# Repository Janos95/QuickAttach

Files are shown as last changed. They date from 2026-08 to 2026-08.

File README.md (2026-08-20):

# SO-101 powered magnetic quick changer v0.2

This is a retrofit, passively docked quick changer for an existing SO-101. Two
permanent magnets perform forgiving capture and face preload; they are **not**
the safety lock. A spring-return stainless keyhole slider positively captures
two metal pull studs. The passive rack cams that slider open, so the robot only
needs straight approach/withdrawal and one rack-exit translation—no wrist
twist, release servo, solenoid, or electromagnet.

The same interface carries power and the existing half-duplex TTL bus. The
first tool can therefore be the standard SO-101 gripper on a detachable adapter
plate while its STS3215 remains motor ID 6.

The calibrated arm model, mesh assets, and stock-gripper STEP used here are
derived from TheRobotStudio/SO-ARM100. Exact source revision and license details
are recorded in the repository-root `THIRD_PARTY_NOTICES.md`.

## What is where

- **Robot side:** 48 x 48 x 9.5 mm main plate, plus a left electrical wing;
  overall envelope 60 x 48 mm. It replaces the gripper at the four existing
  holes on the measured 9.9 mm-square wrist-horn pattern.
- **Magnets:** two purple 12 x 12 x 4 mm blocks, flush in the robot plate at
  `(x, y) = (0, -16)` and `(0, +16)` mm. Each is mechanically fastened, not
  glued.
- **Tool side:** 56 x 50 x 9.5 mm main plate, overall envelope 64 x 50 mm. It
  carries two matching 12 x 12 x 3 mm Q235 steel targets, not more magnets, so
  tool polarity is irrelevant.
- **Location:** two 3.5 mm tapered pins; the second socket is tangentially
  relieved to avoid an over-constrained fit.
- **Positive lock:** two 4 mm pull-stud shoulders enter 6.5 mm keyholes. On
  leaving the rack, the E-GUL4-10 return spring shifts a 1.6 mm stainless slider
  by 3 mm so 4.25 mm necks sit under the 6 mm stud heads. The printed roof, not
  the M2 guide screw, reacts separation load. Loss of power leaves it locked.
- **Electrical interface:** four Mill-Max pins on 5 mm pitch: GND, +12 V,
  TTL_DATA, and a spare TOOL_ID line. GND protrudes 0.2 mm farther so it mates
  first and breaks last.

In the CAD and MuJoCo model, purple identifies the two magnets, silver their
targets and pull studs, green the positive-lock slider, and gold the four
contacts. Use the full-arm MuJoCo example below as the executable acceptance
check.

## Attach and detach sequence

1. Approach the docked tool axially. Tapered locators enter first; magnets then
   close the final gap and compress the contacts.
2. Verify contact—for the first gripper, read servo ID 6 with torque still off.
3. Translate out of the rack. The rack releases the slider tab and the spring
   closes the positive lock.
4. Enable the tool and work normally.
5. To detach, command gripper torque off and stop bus packets, then return the
   still-locked assembly to the rack.
6. During the final rack travel, the fixed wedge pushes the exposed tab 3 mm,
   aligning both large keyholes with the stud heads.
7. The rack retains the tool plate while the arm withdraws axially. Contacts and
   magnets separate; no powered release actuator is involved.

The MuJoCo model uses conditional welds for capture and lock state. It validates
this state sequence and geometry; it does not predict magnetic fields, contact
arcing, printed-part strength, fatigue, or wear.

## Full SO-101 detachable-gripper MuJoCo example

`sim/so101_gripper_change_demo.py` builds on the calibrated upstream
`Simulation/SO101/so101_new_calib.xml` rather than a simplified arm. At load
time it makes one deliberate topology change:

- motor 5's `wrist_roll` joint stays on the robot and receives the v0.2 robot
  plate;
- the exact stock fixed-gripper and moving-jaw mesh subtree, including the
  original `gripper` joint and actuator, moves onto
  `so101_stock_gripper_tool_plate.stl` as a free docked tool;
- that existing gripper actuator represents the normal Feetech ID-6 control
  path after the pogo-pin bus is connected.

The deterministic sequence begins with a 55 mm gap, approaches the dock with
constant coupling orientation, changes from a rack weld to magnetic capture,
changes to the fail-locked positive-lock constraint as the arm withdraws, then
opens and closes the stock jaw through the unchanged gripper actuator. It then
returns the still-locked tool to the rack, switches off the simulated bus,
opens the rack-actuated lock, and withdraws the bare wrist. It exits nonzero
unless the complete attach/lock/use/return/release cycle, 45+ mm withdrawal in
both directions, coupling retention, and at least 0.8 rad of ID-6 jaw travel
are all observed.

From the repository root:

```bash
.venv/bin/pip install -r Simulation/SO101/requirements.txt
.venv/bin/python QuickChange/SO101_Magnetic/sim/so101_gripper_change_demo.py
```

For CI or a machine without a display:

```bash
.venv/bin/python QuickChange/SO101_Magnetic/sim/so101_gripper_change_demo.py --headless
```

The canonical presentation is the interactive Three.js app in
[`web/quickattach-control`](web/quickattach-control). It starts with a bare
wrist and all three tools in the printable fixture, supports orbit/top camera
control, joint controls, and a flange gizmo for moving, attaching, detaching,
and returning tools. Its CAD tab compares each source STL with the emitted
collision geometry.

The same browser scene is also the only video renderer. Run the page locally,
then use `web/quickattach-control/scripts/render-threejs-video.py` to drive it
through Playwright and encode an MP4 with FFmpeg. See the web app README for
exact commands. MuJoCo/Python remain the numerical validation authority; the
page and video are presentation views, not physical-release evidence.

The XML file beside the controller is a scene overlay. The controller merges it
with the upstream robot in memory so there is no duplicated SO-101 description
to fall out of sync. `--save-preview PATH.png` is optional and requires a
working OpenGL/EGL/OSMesa backend.

This simulation intentionally treats magnetic seating and the positive lock as
switched weld constraints. It checks kinematics, model topology, sequencing,
retention, and continued jaw control. It does **not** simulate field strength,
rack-cam contact, slider motion, electrical hot-plug behavior, compliance,
strength, fatigue, or wear. The ID-6 handshake is a state-machine gate rather
than a serial-protocol emulation, and quick-changer/gripper collision geometry
is disabled, so this demo does not prove physical clearance. The physical
validation plan below still applies.

## Retrofitting the standard gripper

The official assembly guide attaches the gripper to motor 5's wrist horn with
four M3x6 screws. This adapter uses that same interface and does not require
drilling or cutting the arm.

1. Power the arm down and remove the four M3x6 gripper-to-horn screws.
2. Fit the robot plate to the existing horn with four M3x10 socket-head screws.
   Confirm at least 3 mm thread engagement and no bottoming on the actual horn
   before tightening; shorten only if the particular horn requires it.
3. Install four Ruthex RX-M3x5.7 inserts in the rear of
   `so101_stock_gripper_tool_plate`.
4. Drop the two DIN 934 M3 pull-stud nuts into their rear hex pockets and fit
   the two shoulder screws from the coupling side. The gripper body captures
   the nuts when installed.
5. Attach the original printed gripper body to the tool plate with its original
   four M3x6 screws.
6. Terminate the gripper motor's three conductors on P1-P3 of the tool PCB:
   GND, +12 V, TTL_DATA. Use the four plated wire holes accessible from the rear.
7. Add a short, reversible adapter harness from the wrist-roll motor's outgoing
   gripper connector to the four robot-side pogo pins. Avoid cutting the stock
   cable; use mating 3-pin housings or a small inline adapter.

The stock gripper keeps ID 6 and is still controlled through the normal LeRobot
Feetech bus. P4 is unused for this first tool. A later controller can read P4
with a pull-up and a tool-specific resistor to ground for passive tool ID.

### Electrical mating caveat

The cited Feetech material specifies 12 V operation and half-duplex serial
control, but does not qualify the servo connector for live hot-plugging. For
the minimum retrofit, command ID 6 torque off, stop bus traffic, mate or unmate,
then verify communication before re-enabling torque. For unattended repeated
tool changing, add a robot-side switched/e-fused +12 V tool branch and enable it
only after mechanical attachment; this is an electrical reliability upgrade,
not an electromagnet.

The supplied target PCB is functional rather than just a drawing: each 4 mm
ENIG target is routed to a rear-accessible plated hole. Fabricate it as 1.0 mm
FR-4, 2 oz copper, ENIG. `electrical_pinout.csv`, the KiCad source, and an SVG
fab drawing are included. Retain the PCB by bonding only its perimeter into the
recess with an electronics-compatible epoxy; keep the ENIG targets free of
adhesive and verify that the board remains flush.

## Purchasable hardware

| Qty | Side | Part | Geometry / purpose |
|---:|---|---|---|
| 2 | robot | [Supermagnete CS-Q-12-12-04-N](https://www.supermagnete.de/eng/screw-on-neodymium-magnets/screw-on-block-magnet-12-x-12-x-4mm_CS-Q-12-12-04-N), EAN 7640172691830 | N35 NdFeB, 12 x 12 x 4 mm, M3 countersunk hole, 29.4 N nominal axial force each |
| 2/tool | tool | [Supermagnete MC-12-12-03](https://www.supermagnete.de/eng/magnet-counterparts-to-screw-on/metal-plates-with-countersunk-hole-12-x-12-x-3mm_MC-12-12-03), EAN 7640172691892 | Q235 target, 12 x 12 x 3 mm, M5 countersunk hole |
| 2/tool | tool | [McMaster 90318A720](https://www.mcmaster.com/90318A720/) | 316 SS ultra-low-profile shoulder screw; M3 thread, 4 mm shoulder diameter, 5 mm shoulder length, 6 x 1.3 mm head, 4 mm thread length |
| 2/tool | tool | [DIN 934 M3 nut](https://accu-components.com/us/hexagon-nuts/7888-HPN-M3-A2) | 5.5 mm across flats x 2.4 mm; captive pull-stud retention |
| 1 | robot | [MISUMI E-GUL4-10](https://us.misumi-ec.com/vona2/detail/110310903689/?HissuCode=E-GUL4-10) | 304 SS compression spring, OD 4 x 10 mm free, 0.98 N/mm, 4 mm permitted deflection |
| 4 | robot | [Mill-Max 7983-1-15-20-75-14-11-0](https://www.mill-max.com/products/discrete-spring-loaded-pins/spring-loaded-pin-with-solder-cup-termination/7983/7983-1-15-20-75-14-11-0) | Solder-cup spring pin, drawing Ø1.0668 mm plunger and 1.397 ± 0.127 mm full stroke. This design selects solder-cup-first knurl retention: Ø1.58 mm land, separate Ø2.31 mm body counterbore, and shoulder hard-stop. Process fit/pull-out and installed reliability remain unqualified. |
| 4 | gripper tool | [Ruthex RX-M3x5.7](https://www.ruthex.de/en/products/ruthex-gewindeeinsatz-m3-100-stuck-rx-m3x5-7-messing-gewindebuchsen) | M3 heat-set inserts for the original gripper-hole pattern |

Standard fasteners per robot: four M3x10 socket-head wrist screws, two ISO
10642 M3x10 countersunk magnet screws with two DIN 934 M3 nuts, and one flush
M2x6 slider guide screw. Per tool: two ISO 10642 M5x10 countersunk target screws
with two DIN 934 M5 nuts. Tighten the brittle magnets by hand only.

## Load basis and why the lock is required

There is no whole-arm payload figure in the official SO-101 documentation used
for this design. The official follower uses six STS3215 motors; Feetech gives
the servo a **10 kg.cm rated torque** and **30 kg.cm peak stall torque** at 12 V,
equivalent to 0.9807 and 2.942 N.m. Servo torque is not an arm payload rating:
arm pose, link mass, lever arm, acceleration, thermal limits, print strength,
and collision loads all matter.

For intuition only, 1 kg at a 100 mm horizontal lever is about 0.981 N.m before
adding the tool, adapter, robot links, or dynamics. It therefore must not be
presented as a supported 1 kg SO-101 payload.

The generated stock-gripper pair contains about 46.3 cm3 of printed plate
material, roughly 47 g if made from 1.01 g/cm3 PA12. Magnets, targets, slider,
contacts, PCB, nuts, screws, spring, and harness will put the real adapter pair
roughly in the 65-75 g range; weigh the finished parts and include that mass and
its offset in the robot load model.

The two selected magnets have 58.8 N combined catalog pull only at their ideal
test condition. With a 16 mm moment arm, the optimistic magnet-only pry estimate
is 0.9408 N.m—already below the servo's 0.9807 N.m rated-torque reference. Air
gaps, coatings, edge loading, and shock reduce real holding force further.
Magnets alone are therefore rejected.

The positive lock is sized to be physically proof-tested at 2.942 N.m, three
times the servo rated-torque reference. At a 24 mm interface edge that is about
122.6 N total reaction, or 61.3 N per pull stud if sharing is equal. This is a
**test target**, not a certification or a claim that every printed assembly
will pass. Test both bending axes because load sharing will not be perfectly
equal.

A conventional electromagnet is not recommended here: it adds wiring, heat,
and a drop-on-power-loss failure mode. Permanent magnets plus the spring-closed
metal lock are simpler and fail locked. Consider an electro-permanent magnet
only if release away from the rack becomes a hard requirement.

Official references: [SO-101 assembly and motor IDs](https://huggingface.co/docs/lerobot/so101),
[Feetech STS3215 specifications](https://www.feetechrc.com/525603.html), and
[Feetech three-wire pinout PDF](https://www.feetechrc.com/Data/feetechrc/upload/file/20240428/6384991403763545451893182.pdf).

## Fabrication

- Print robot and tool plates in PA12/SLS nylon or a well-characterized PA-CF
  process for load tests. Tough PETG is acceptable for early light-duty
  prototypes; PLA is for fit checks only.
- For FDM, start at 0.2 mm layers, at least five perimeters, five top/bottom
  layers, and 40% infill. Print the large rear face down and mating features up.
- Laser- or waterjet-cut the working slider from 1.5-1.6 mm 304 stainless using
  `so101_positive_lock_slider_profile.dxf`. The slider STL is a fit-check model,
  not the working load-bearing part. Deburr and polish both faces and keyholes.
- The CAD now implements one specific Mill-Max mounting mode rather than a
  straight pilot: insert the solder-cup side first through a Ø1.58 mm knurl
  land into a separate Ø2.31 mm body counterbore, stopping the shoulder on
  the signal-specific internal ledge. This is dimensionally reconstructed from
  the official drawing and [press-fit application note](https://www.mill-max.com/sites/default/files/external/assets/2020-10/spring-loaded_solder-cup_pin_2.pdf),
  but it is **not released for fabrication** until a process-specific coupon
  establishes bore tolerance, insertion force, and pull-out retention. The
  nominal GND shoulder datum is 0.20 mm ahead; four independent ±0.1524 mm
  drawing-length terms yield a conservative worst-case lead of -0.4096 mm, so
  first-mate is not qualified.
- Manufacturer artwork is not redistributed because its redistribution terms
  were not established. The derived ledger at
  `QuickChange/SO101_Magnetic/source_authority/millmax_7983/authority_ledger.json`
  records the official URLs, byte counts, SHA-256 digests, exact inch callouts,
  and this provenance limitation. The reconstructed solids are
  official-drawing-derived nominal collision envelopes, not official Mill-Max
  3D CAD; deterministic generation uses the checked-in ledger and never
  silently refetches mutable web content.
- Keep magnets and steel targets flush to 0.05 mm below their mating faces so
  impact lands on printed face lands, not brittle nickel plating.
- The current exact CAD leaves 0.0499 mm after its route interval and 0.20 mm
  clearance deductions using an unqualified local motion allowance. That
  number is arithmetic residue, not a sampled route or an SLS/FDM or
  catalog-part tolerance. Release remains blocked until a process/fit coupon
  qualifies the combined error budget. The pogo exterior is a conservative
  nominal drawing-derived envelope with unqualified part/process tolerances;
  knurl pull-out, installed electrical cycling, and magnetic fastener
  seating/preload still need physical evidence. Do not fabricate the
  electrical mounting interface from this checkpoint.
- Check that the slider moves the full 3.0 mm without binding. At the current
  endpoints the spring is 9.4 mm locked and 6.4 mm unlocked: 3.6 mm maximum
  compression, leaving 0.4 mm margin to the catalog deflection limit.

## Rolled core-dock source and runtime geometric checkpoint

The magnetic core-dock source now publishes a `-87.21086925015224 deg`
tool-view roll that makes dock-local `-Y` world-up, plus a deterministic
31-row, 0.5 mm release continuation. Its canonical roster SHA-256 is
`f30b0c178917945fcd45358710e5127302bc5240ca6cb4cdaa7f49d16c4f0293`.

A separate one-solid hollow pedestal closes the dock to the floor through two
M4 stop fasteners and four M6 floor fasteners. The exact source BRep volumes
are 7379.269784962569 mm3 for the countersunk stop, 21743.904784962568 mm3 for
the dock, and 162415.4180526403 mm3 for the support, for an installed printed
total of 184159.32283760287 mm3. Positive material overlaps join the support
head/post (716.8886804667 mm3) and post/base (1248 mm3); the zero-distance
dock/support interface is explicitly bolted and is not a collision allowlist.
The earlier 162308.50715898623 mm3 support estimate is superseded by the exact
Boolean result.

The committed
`QuickChange/SO101_Magnetic/sim/rolled_core_dock_runtime_report.json`
replays the exact 31-row roster in the compiled rolled frame. Its maximum row
FK errors are `1.3645432973688894e-13 mm` and
`6.990106082579211e-16 rad`. The bounded screen evaluates 14 upstream arm
meshes against 90 static core-dock targets over 301 joint-linear states
(`30 * 10 + 1`), or 379260 pair evaluations. The
`4.3592095380000915 mm` sampled lower bound minus the
`0.13870802188957512 mm` pair-specific topology motion bound gives a
`4.220501516110517 mm` continuous lower bound, above the required `0.20 mm`.
The 11-piece support proxy retains a separate
`16.201539960841686 mm` continuous lower bound. Startup has 65 intended
tangent contacts and zero penetrations, and the support chain has 15 verified
tangencies.

That evidence closes only the exact hash-bound runtime geometric
recomputation for this roster and compiled inventory. It does not authorize
robot self-collision, controller execution/tracking, the physical Matcha base
or floor fixture, contact forces, friction, materials, fasteners, load paths,
reverse insertion, or physical release. `release_ready` remains false pending
normative M4/M6 hardware authority, an authoritative tapped floor substrate,
PA12 material/process/creep allowables, printed dimensional and anchor-strength
qualification, cam contact/friction/reverse-insertion/capture-dynamics
validation, and the existing interface-hardware blockers.

## Generate, inspect, and simulate

From the repository root:

```bash
.venv/bin/pip install -r Simulation/SO101/requirements.txt
.venv/bin/python QuickChange/SO101_Magnetic/generate_cad.py
.venv/bin/python QuickChange/SO101_Magnetic/load_check.py
.venv/bin/python QuickChange/SO101_Magnetic/sim/so101_gripper_change_demo.py --headless
```

The CAD generator exports STEP/STL geometry, a stainless-slider DXF,
illustrative assembly STEP files, design and engineering JSON, and PCB files.
The assemblies are not complete hardware authorities: several fasteners, the
harness, and the exact purchased pogo section are still absent. The older
isolated-coupler demo remains useful for constraint debugging, while the
full-arm demo is a development integration example, not an acceptance check.
The clearance validator deliberately keeps `release_ready` false until the
machine-readable interface blockers are closed.

## Required physical validation

This remains a prototype, not a safety-rated tool changer. Before robot use:

1. Gauge every printed pocket, locator, stud, slider, and pogo fit before
   installing magnets or electronics.
2. Perform axial pull, shear, and edge-pry tests on the assembled interface.
3. Proof both bending axes to 2.942 N.m behind a guard, then inspect the printed
   roof, captive-nut floors, stud heads, slider keyholes, and fasteners.
4. Cycle attach/lock/unlock/release at least 1,000 times while monitoring slider
   travel, contact resistance, pogo temperature, magnet damage, and screw
   loosening.
5. Start robot trials at low speed over a padded surface with a tether and a
   payload far below the demonstrated test limit. Never put people under a
   retained tool or payload.

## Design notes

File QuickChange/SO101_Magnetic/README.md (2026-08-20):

# SO-101 powered magnetic quick changer v0.2

This is a retrofit, passively docked quick changer for an existing SO-101. Two
permanent magnets perform forgiving capture and face preload; they are **not**
the safety lock. A spring-return stainless keyhole slider positively captures
two metal pull studs. The passive rack cams that slider open. A narrow axial
lead couples the last 3.2 mm of approach to a 0.20-to-0.00 mm lateral recenter;
the existing X/Y wedge then controls spring return during rack exit. No release
servo, solenoid, or electromagnet is required.

The same interface carries power and the existing half-duplex TTL bus. The
first tool can therefore be the standard SO-101 gripper on a detachable adapter
plate while its STS3215 remains motor ID 6.

The calibrated arm model, mesh assets, and stock-gripper STEP used here are
derived from TheRobotStudio/SO-ARM100. Exact source revision and license details
are recorded in the repository-root `THIRD_PARTY_NOTICES.md`.

## What is where

- **Robot side:** 48 x 48 x 9.5 mm main plate, plus a left electrical wing;
  overall envelope 60 x 48 mm. It replaces the gripper at the four existing
  holes on the measured 9.9 mm-square wrist-horn pattern.
- **Magnets:** two purple 12 x 12 x 4 mm blocks, flush in the robot plate at
  `(x, y) = (0, -16)` and `(0, +16)` mm. Each is mechanically fastened, not
  glued.
- **Tool side:** 56 x 50 x 9.5 mm main plate, overall envelope 64 x 50 mm. It
  carries two matching 12 x 12 x 3 mm Q235 steel targets, not more magnets, so
  tool polarity is irrelevant.
- **Location:** two 3.5 mm tapered pins; the second socket is tangentially
  relieved to avoid an over-constrained fit.
- **Positive lock:** two 4 mm pull-stud shoulders enter 6.5 mm keyholes. On
  leaving the rack, the E-GUL4-10 return spring shifts a 1.6 mm stainless slider
  by 3 mm so 4.25 mm necks sit under the 6 mm stud heads. Each neck is a 7.25 mm
  capsule covering the complete 3 mm shoulder-centre path, not a short
  centre-to-centre rectangle. It provides 0.125 mm radial shoulder clearance
  and 0.875 mm radial head-retention overlap. The printed roof, not the M2 guide
  screw, reacts separation load. Loss of power leaves it locked.
- **Cam corridor:** the passive cam retains its `x = 24.05 mm` unlock datum and
  rack-exit wedge. Its integral source lead is a 45-degree ruled loft from
  `x = 27.25` at `z = -9.60` mm to `x = 24.05` at `z = -6.40` mm over the
  narrow `y = 0..2` mm tab land. A vertical finger joins the main wedge, and a
  1 mm root bridge at `x = 28..29` mm lies beyond the locked tab's `x = 27` mm
  maximum. The full-depth robot-plate recess preserves the certified approach
  clearance without changing slider travel, keyhole alignment, or retention.
- **Electrical interface:** four Mill-Max pins on 5 mm pitch: GND, +12 V,
  TTL_DATA, and a spare TOOL_ID line. GND protrudes 0.2 mm farther so it mates
  first and breaks last.

In the CAD and MuJoCo model, purple identifies the two magnets, silver their
targets and pull studs, green the positive-lock slider, and gold the four
contacts. Use the full-arm MuJoCo example below as the executable acceptance
check.

## Attach and detach sequence

1. Approach at the published +0.20 mm open-side offset. From 6.4 to 3.2 mm
   preseated, recenter linearly to zero while the 45-degree lead opens the
   slider to `q <= 0.05 mm`. This finishes before the stud heads first reach
   the slider plane at 3.1 mm preseated.
2. Continue axially at zero offset. Tapered locators enter first; magnets then
   close the final gap while the hold finger keeps the keyhole entries open.
3. Verify contact—for the first gripper, read servo ID 6 with torque still off.
4. Translate in dock-local -Y. The main wedge permits spring return after the
   first 2 mm; `q = 3 mm` is reached at 13.9494 mm and has 0.2518 mm exact cam
   clearance at the nominal 15 mm witness.
5. Enable the tool and work normally.
6. To detach, command gripper torque off and stop bus packets, then return the
   still-locked assembly to the rack.
7. During the final rack travel, the fixed wedge pushes the exposed tab 3 mm,
   aligning both large keyholes with the stud heads.
8. The rack retains the tool plate while the arm withdraws axially. Contacts and
   magnets separate; no powered release actuator is involved.

The MuJoCo model uses conditional welds for capture and lock state. It validates
this state sequence and geometry; it does not predict magnetic fields, contact
arcing, printed-part strength, fatigue, or wear.

## CAD/simulation geometry contract

### Collision strategy

The production MuJoCo model uses one collision representation: ordinary,
named rigid geoms. Those geoms are convex in MuJoCo, whether expressed as an
analytic primitive or a mesh. Functional contact regions use small named
primitives; already-convex parts use one mesh; genuinely non-convex parts use
a deterministic set of convex pieces. Rigid flex and SDF collision are not
part of the runtime model.

This keeps contact identity, explicit contact pairs, mass/inertia accounting,
and solver behavior uniform across the robot, changer, tools, and fixture. It
also keeps the model fast enough for the full workcell. Mass properties are
source-derived and must not be inferred from the number of collision pieces.

The offline fidelity check is intentionally narrower than the runtime model:

1. tessellate the selected CAD surface with a known absolute deflection;
2. tessellate the convex runtime pieces with their known error bound;
3. cover both triangle surfaces with bounded witness cells;
4. measure source-to-runtime and runtime-to-source distances using FCPW only
   for candidate selection, replaying the selected triangles in float64; and
5. add both faceting bounds and the witness-cell radius to each observed
   maximum.

Both directed upper bounds must fit the tolerance. The reverse direction is
what rejects extra or hole-filling collision material; the forward direction
rejects missing material. This verifier does not reconstruct topology, perform
signed occupancy, run Boolean unions, or duplicate CAD-kernel containment.
Those operations added a second geometry system without changing the runtime
collision representation.

`generate_cad.py` publishes the exact core dock-stop bounds, stock-gripper STEP
mount, full-depth robot-plate cam-relief bounds, swept keyhole-capsule contract,
and executable passive-cam `p/x/q` and `-Y/q` laws in both
`design_parameters.json` and `exports/core_cad_manifest.json`. The relief
contract also records the 0.20 mm guided approach offset and retained 8.225 mm
stud-well / 7.150 mm slider-lobe ligaments. The stock dock stop is not interchangeable
with the spoon/whisk stops: core bounds are `X[-45,37]`, `Y[26,32]`,
`Z[-3,12.5]` mm, while the two-bay matcha package publishes its own per-bay
contracts. Simulation builders must consume the matching contract rather than
reuse one generic box for all docks.

The calibrated stock-gripper wrapper pose is solved from the live child-geom
transform and the released CAD datum. `sim/validate_cad_clearance.py` records
that composed transform and rejects a nonzero composition residual. It also
checks the complete 0–80 mm rack path, using a focused 0.10 mm grid for the cam
corridor; the 0.50 mm sampled clearance yields a conservative 0.45 mm
continuous bound. A separate exact OCCT sweep checks both 4 mm shoulders every
0.05 mm from unlocked through the full 3.0 mm stroke, verifies the analytic
0.125 mm continuous capsule clearance, confirms that both 6.5 mm entries pass
the heads when unlocked, and confirms projected head retention when locked.
The 15→0 mm capture sweep follows the coupled recenter rather than assuming a
fixed lateral offset. Its 0.3000 mm sampled robot-plate/cam gap minus the full
two-axis half-step motion certifies 0.249902 mm continuous clearance. A tighter
0.01 mm slider/stud sweep certifies 0.205264 mm continuous clearance before the
3.1 mm head-entry event. OCCT also requires zero cam/stud overlap throughout
capture, full component closure, passive -Y return, and at least 0.20 mm q=3
cam clearance at the 15 mm exit witness.

Core exports are timestamp-canonicalized and hash-closed. To verify byte
reproducibility in two temporary directories, run `generate_cad.py` twice with
`--output-dir`; the canonical checked-in generation and exact report are:

```bash
XDG_CACHE_HOME=/tmp/cq-cache .venv/bin/python \
  QuickChange/SO101_Magnetic/generate_cad.py
XDG_CACHE_HOME=/tmp/cq-cache .venv/bin/python \
  QuickChange/SO101_Magnetic/sim/validate_cad_clearance.py
```

`core_cad_manifest.json` excludes itself to avoid circular hashing, but records
the generator, deterministic inventory digest, every contained artifact's
repo-relative path/byte count/SHA-256, and every published geometry contract. The
clearance report separately pins the manifest file record and independently
recomputes its contents.

## Full SO-101 detachable-gripper MuJoCo example

`sim/so101_gripper_change_demo.py` builds on the calibrated upstream
`Simulation/SO101/so101_new_calib.xml` rather than a simplified arm. At load
time it makes one deliberate topology change:

- motor 5's `wrist_roll` joint stays on the robot and receives the v0.2 robot
  plate;
- the exact stock fixed-gripper and moving-jaw mesh subtree, including the
  original `gripper` joint and actuator, moves onto
  `so101_stock_gripper_tool_plate.stl` as a free docked tool;
- that existing gripper actuator represents the normal Feetech ID-6 control
  path after the pogo-pin bus is connected.

The deterministic sequence begins with a 55 mm gap, approaches the dock with
constant coupling orientation, changes from a rack weld to magnetic capture,
changes to the fail-locked positive-lock constraint as the arm withdraws, then
opens and closes the stock jaw through the unchanged gripper actuator. It then
returns the still-locked tool to the rack, switches off the simulated bus,
opens the rack-actuated lock, and withdraws the bare wrist. It exits nonzero
unless the complete attach/lock/use/return/release cycle, 45+ mm withdrawal in
both directions, coupling retention, and at least 0.8 rad of ID-6 jaw travel
are all observed.

From the repository root:

```bash
.venv/bin/pip install -r Simulation/SO101/requirements.txt
.venv/bin/python QuickChange/SO101_Magnetic/sim/so101_gripper_change_demo.py
```

For CI or a machine without a display:

```bash
.venv/bin/python QuickChange/SO101_Magnetic/sim/so101_gripper_change_demo.py --headless
```

The canonical presentation is the interactive Three.js app at
[`../../web/quickattach-control`](../../web/quickattach-control). It exposes
the bare-wrist robot, all three tools, the printable fixture, camera and joint
controls, a draggable flange gizmo, and a CAD-versus-collision inspector.

Its Playwright renderer drives that exact browser scene and encodes it with
FFmpeg; the old CPU-only video scenes have been retired. See the web app README
for local and headless rendering commands. Presentation remains separate from
the MuJoCo/Python validation authority and does not constitute physical-release
evidence.

The XML file beside the controller is a scene overlay. The controller merges it
with the upstream robot in memory so there is no duplicated SO-101 description
to fall out of sync. `--save-preview PATH.png` is optional and requires a
working OpenGL/EGL/OSMesa backend.

This simulation intentionally treats magnetic seating and the positive lock as
switched weld constraints. It checks kinematics, model topology, sequencing,
retention, and continued jaw control. It does **not** simulate field strength,
rack-cam contact, slider motion, electrical hot-plug behavior, compliance,
strength, fatigue, or wear. The ID-6 handshake is a state-machine gate rather
than a serial-protocol emulation, and quick-changer/gripper collision geometry
is disabled, so this demo does not prove physical clearance. The physical
validation plan below still applies.

## Retrofitting the standard gripper

The official assembly guide attaches the gripper to motor 5's wrist horn with
four M3x6 screws. This adapter uses that same interface and does not require
drilling or cutting the arm.

1. Power the arm down and remove the four M3x6 gripper-to-horn screws.
2. Fit the robot plate to the existing horn with four M3x10 socket-head screws.
   Confirm at least 3 mm thread engagement and no bottoming on the actual horn
   before tightening; shorten only if the particular horn requires it.
3. Install four Ruthex RX-M3x5.7 inserts in the rear of
   `so101_stock_gripper_tool_plate`.
4. Drop the two DIN 934 M3 pull-stud nuts into their rear hex pockets and fit
   the two shoulder screws from the coupling side. The gripper body captures
   the nuts when installed.
5. Attach the original printed gripper body to the tool plate with its original
   four M3x6 screws.
6. Terminate the gripper motor's three conductors on P1-P3 of the tool PCB:
   GND, +12 V, TTL_DATA. Use the four plated wire holes accessible from the rear.
7. Add a short, reversible adapter harness from the wrist-roll motor's outgoing
   gripper connector to the four robot-side pogo pins. Avoid cutting the stock
   cable; use mating 3-pin housings or a small inline adapter.

The stock gripper keeps ID 6 and is still controlled through the normal LeRobot
Feetech bus. P4 is unused for this first tool. A later controller can read P4
with a pull-up and a tool-specific resistor to ground for passive tool ID.

### Electrical mating caveat

The cited Feetech material specifies 12 V operation and half-duplex serial
control, but does not qualify the servo connector for live hot-plugging. For
the minimum retrofit, command ID 6 torque off, stop bus traffic, mate or unmate,
then verify communication before re-enabling torque. For unattended repeated
tool changing, add a robot-side switched/e-fused +12 V tool branch and enable it
only after mechanical attachment; this is an electrical reliability upgrade,
not an electromagnet.

The supplied target PCB is functional rather than just a drawing: each 4 mm
ENIG target is routed to a rear-accessible plated hole. Fabricate it as 1.0 mm
FR-4, 2 oz copper, ENIG. `electrical_pinout.csv`, the KiCad source, and an SVG
fab drawing are included. Retain the PCB by bonding only its perimeter into the
recess with an electronics-compatible epoxy; keep the ENIG targets free of
adhesive and verify that the board remains flush.

## Purchasable hardware

| Qty | Side | Part | Geometry / purpose |
|---:|---|---|---|
| 2 | robot | [Supermagnete CS-Q-12-12-04-N](https://www.supermagnete.de/eng/screw-on-neodymium-magnets/screw-on-block-magnet-12-x-12-x-4mm_CS-Q-12-12-04-N), EAN 7640172691830 | N35 NdFeB, 12 x 12 x 4 mm, M3 countersunk hole, 29.4 N nominal axial force each |
| 2/tool | tool | [Supermagnete MC-12-12-03](https://www.supermagnete.de/eng/magnet-counterparts-to-screw-on/metal-plates-with-countersunk-hole-12-x-12-x-3mm_MC-12-12-03), EAN 7640172691892 | Q235 target, 12 x 12 x 3 mm, M5 countersunk hole |
| 2/tool | tool | [McMaster 90318A720](https://www.mcmaster.com/90318A720/) | 316 SS ultra-low-profile shoulder screw; M3 thread, 4 mm shoulder diameter, 5 mm shoulder length, 6 x 1.3 mm head, 4 mm thread length |
| 2/tool | tool | [DIN 934 M3 nut](https://accu-components.com/us/hexagon-nuts/7888-HPN-M3-A2) | 5.5 mm across flats x 2.4 mm; captive pull-stud retention |
| 1 | robot | [MISUMI E-GUL4-10](https://us.misumi-ec.com/vona2/detail/110310903689/?HissuCode=E-GUL4-10) | 304 SS compression spring, OD 4 x 10 mm free, 0.98 N/mm, 4 mm permitted deflection |
| 4 | robot | [Mill-Max 7983-1-15-20-75-14-11-0](https://www.mill-max.com/products/discrete-spring-loaded-pins/spring-loaded-pin-with-solder-cup-termination/7983/7983-1-15-20-75-14-11-0) | Solder-cup spring pin, drawing Ø1.0668 mm plunger and 1.397 ± 0.127 mm full stroke. This design selects solder-cup-first knurl retention: Ø1.58 mm land, separate Ø2.31 mm body counterbore, and shoulder hard-stop. Process fit/pull-out and installed reliability remain unqualified. |
| 4 | gripper tool | [Ruthex RX-M3x5.7](https://www.ruthex.de/en/products/ruthex-gewindeeinsatz-m3-100-stuck-rx-m3x5-7-messing-gewindebuchsen) | M3 heat-set inserts for the original gripper-hole pattern |

Standard fasteners per robot: four M3x10 socket-head wrist screws, two ISO
10642 M3x10 countersunk magnet screws with two DIN 934 M3 nuts, and one flush
M2x6 slider guide screw. Per tool: two ISO 10642 M5x10 countersunk target screws
with two DIN 934 M5 nuts. Tighten the brittle magnets by hand only.

## Load basis and why the lock is required

There is no whole-arm payload figure in the official SO-101 documentation used
for this design. The official follower uses six STS3215 motors; Feetech gives
the servo a **10 kg.cm rated torque** and **30 kg.cm peak stall torque** at 12 V,
equivalent to 0.9807 and 2.942 N.m. Servo torque is not an arm payload rating:
arm pose, link mass, lever arm, acceleration, thermal limits, print strength,
and collision loads all matter.

For intuition only, 1 kg at a 100 mm horizontal lever is about 0.981 N.m before
adding the tool, adapter, robot links, or dynamics. It therefore must not be
presented as a supported 1 kg SO-101 payload.

The generated stock-gripper pair contains about 46.3 cm3 of printed plate
material, roughly 47 g if made from 1.01 g/cm3 PA12. Magnets, targets, slider,
contacts, PCB, nuts, screws, spring, and harness will put the real adapter pair
roughly in the 65-75 g range; weigh the finished parts and include that mass and
its offset in the robot load model.

The two selected magnets have 58.8 N combined catalog pull only at their ideal
test condition. With a 16 mm moment arm, the optimistic magnet-only pry estimate
is 0.9408 N.m—already below the servo's 0.9807 N.m rated-torque reference. Air
gaps, coatings, edge loading, and shock reduce real holding force further.
Magnets alone are therefore rejected.

The positive lock is sized to be physically proof-tested at 2.942 N.m, three
times the servo rated-torque reference. At a 24 mm interface edge that is about
122.6 N total reaction, or 61.3 N per pull stud if sharing is equal. This is a
**test target**, not a certification or a claim that every printed assembly
will pass. Test both bending axes because load sharing will not be perfectly
equal.

A conventional electromagnet is not recommended here: it adds wiring, heat,
and a drop-on-power-loss failure mode. Permanent magnets plus the spring-closed
metal lock are simpler and fail locked. Consider an electro-permanent magnet
only if release away from the rack becomes a hard requirement.

Official references: [SO-101 assembly and motor IDs](https://huggingface.co/docs/lerobot/so101),
[Feetech STS3215 specifications](https://www.feetechrc.com/525603.html), and
[Feetech three-wire pinout PDF](https://www.feetechrc.com/Data/feetechrc/upload/file/20240428/6384991403763545451893182.pdf).

## Fabrication

- Print robot and tool plates in PA12/SLS nylon or a well-characterized PA-CF
  process for load tests. Tough PETG is acceptable for early light-duty
  prototypes; PLA is for fit checks only.
- For FDM, start at 0.2 mm layers, at least five perimeters, five top/bottom
  layers, and 40% infill. Print the large rear face down and mating features up.
- Laser- or waterjet-cut the working slider from 1.5-1.6 mm 304 stainless using
  `so101_positive_lock_slider_profile.dxf`. The slider STL is a fit-check model,
  not the working load-bearing part. Deburr and polish both faces and keyholes.
- The CAD now implements one specific Mill-Max mounting mode rather than a
  straight pilot: insert the solder-cup side first through a Ø1.58 mm knurl
  land into a separate Ø2.31 mm body counterbore, stopping the shoulder on
  the signal-specific internal ledge. This is dimensionally reconstructed from
  the official drawing and [press-fit application note](https://www.mill-max.com/sites/default/files/external/assets/2020-10/spring-loaded_solder-cup_pin_2.pdf),
  but it is **not released for fabrication** until a process-specific coupon
  establishes bore tolerance, insertion force, and pull-out retention. The
  nominal GND shoulder datum is 0.20 mm ahead; four independent ±0.1524 mm
  drawing-length terms yield a conservative worst-case lead of -0.4096 mm, so
  first-mate is not qualified.
- Manufacturer artwork is not redistributed because its redistribution terms
  were not established. The derived ledger at
  `source_authority/millmax_7983/authority_ledger.json` records the official
  URLs, byte counts, SHA-256 digests, exact inch callouts, and this provenance
  limitation. The reconstructed solids are official-drawing-derived nominal
  collision envelopes, not official Mill-Max 3D CAD; deterministic generation
  uses the checked-in ledger and never silently refetches mutable web content.
- Keep magnets and steel targets flush to 0.05 mm below their mating faces so
  impact lands on printed face lands, not brittle nickel plating.
- The current exact CAD leaves 0.0499 mm after its route interval and 0.20 mm
  clearance deductions using an unqualified local motion allowance. That
  number is arithmetic residue, not a sampled route or an SLS/FDM or
  catalog-part tolerance. Release remains blocked until a process/fit coupon
  qualifies the combined error budget. The pogo exterior is a conservative
  nominal drawing-derived envelope with unqualified part/process tolerances;
  knurl pull-out, installed electrical cycling, and magnetic fastener
  seating/preload still need physical evidence. Do not fabricate the
  electrical mounting interface from this checkpoint.
- Check that the slider moves the full 3.0 mm without binding. At the current
  endpoints the spring is 9.4 mm locked and 6.4 mm unlocked: 3.6 mm maximum
  compression, leaving 0.4 mm margin to the catalog deflection limit.

## Rolled core-dock source and runtime geometric checkpoint

The core interface now has a source-only installation contract for a
`-87.21086925015224 deg` tool-view roll about the mating normal. Its published
world pose is `(0.19082795371216685, 0.1330713713445051,
0.1939154579377553) m`, quaternion `wxyz=(0.6440855284765126,
-0.6440855284765125, 0.2918112952014223, -0.2918112952014225)`. In that frame,
dock-local `-Y` is world-up. The exact 0–15 mm release continuation has 31
rows at 0.5 mm, SHA-256
`f30b0c178917945fcd45358710e5127302bc5240ca6cb4cdaa7f49d16c4f0293`,
and a 0.2360031833 deg maximum joint step.

The dock remains a separate one-solid BRep and bolts to a hollow floor
pedestal. The pedestal is a one-solid 43 mm square / 35 mm square hollow post
with 4 mm walls, a 100 x 80 x 8 mm floor plate, a 56 x 8 x 8.5 mm head, and a
right bolt reinforcement. Its exact post/head and post/base positive overlaps
are 716.8886804667 and 1248 mm3 after the hardware cuts. Two countersunk M4
fasteners join the stop to the head; four countersunk M6 fasteners join the
base to a future tapped fixture. The source BReps close at:

- stop: 7379.269784962569 mm3;
- complete dock: 21743.904784962568 mm3;
- support: 162415.4180526403 mm3;
- installed printed total: 184159.32283760287 mm3.

The earlier 162308.50715898623 mm3 support estimate was not the volume of the
specified Boolean construction and is superseded. No material mass is claimed
until material condition and density are selected. The minimum fixed-feature
clearance is 1.0 mm; the explicit 0.70 mm nominal tolerance allocation leaves
0.30 mm arithmetic residue, but the print process is not qualified. The
screening-only 1.5 GPa load proxy gives 4.25271213611 N.m combined moment,
0.5720 MPa bending stress, and 0.1940 mm tip deflection; these are not material
or joint allowables.

The committed `sim/rolled_core_dock_runtime_report.json` replays the exact
31-row roster in the compiled rolled frame. Its maximum row FK errors are
`1.3645432973688894e-13 mm` and `6.990106082579211e-16 rad`. The bounded
screen evaluates 14 upstream arm meshes against 90 static core-dock targets
over 301 joint-linear states (`30 * 10 + 1`), or 379260 pair evaluations. The
`4.3592095380000915 mm` sampled lower bound minus the
`0.13870802188957512 mm` pair-specific topology motion bound gives a
`4.220501516110517 mm` continuous lower bound, above the required `0.20 mm`.
The 11-piece support proxy retains a separate
`16.201539960841686 mm` continuous lower bound. Startup has 65 intended
tangent contacts and zero penetrations, and the support chain has 15 verified
tangencies.

That evidence closes only the exact hash-bound runtime geometric
recomputation for this roster and compiled inventory. It does not authorize
robot self-collision, controller execution/tracking, the physical Matcha base
or floor fixture, contact forces, friction, materials, fasteners, load paths,
reverse insertion, or physical release. `release_ready` remains false pending
normative M4/M6 hardware authority, an authoritative tapped floor substrate,
PA12 material/process/creep allowables, printed dimensional and anchor-strength
qualification, cam contact/friction/reverse-insertion/capture-dynamics
validation, and the existing interface-hardware blockers.

## Generate, inspect, and simulate

From the repository root:

```bash
.venv/bin/pip install -r Simulation/SO101/requirements.txt
.venv/bin/python QuickChange/SO101_Magnetic/generate_cad.py
.venv/bin/python QuickChange/SO101_Magnetic/load_check.py
.venv/bin/python QuickChange/SO101_Magnetic/sim/so101_gripper_change_demo.py --headless
```

The CAD generator exports STEP/STL geometry, a stainless-slider DXF,
illustrative assembly STEP files, design and engineering JSON, and PCB files.
The assemblies are not complete hardware authorities: several fasteners, the
harness, and the exact purchased pogo section are still absent. The older
isolated-coupler demo remains useful for constraint debugging, while the
full-arm demo is a development integration example, not an acceptance check.
The clearance validator deliberately keeps `release_ready` false until the
machine-readable interface blockers are closed.

## Required physical validation

This remains a prototype, not a safety-rated tool changer. Before robot use:

1. Gauge every printed pocket, locator, stud, slider, and pogo fit before
   installing magnets or electronics.
2. Perform axial pull, shear, and edge-pry tests on the assembled interface.
3. Proof both bending axes to 2.942 N.m behind a guard, then inspect the printed
   roof, captive-nut floors, stud heads, slider keyholes, and fasteners.
4. Cycle attach/lock/unlock/release at least 1,000 times while monitoring slider
   travel, contact resistance, pogo temperature, magnet damage, and screw
   loosening.
5. Start robot trials at low speed over a padded surface with a tether and a
   payload far below the demonstrated test limit. Never put people under a
   retained tool or payload.

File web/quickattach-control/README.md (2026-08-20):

# QuickAttach Robot Control

An interactive Three.js view of the source-bound SO-101 QuickAttach MuJoCo
workcell. The robot starts with a bare wrist. Three detachable end effectors
sit in a printable, bench-fastened rack with their mating flanges open toward
the robot.

There is no scripted animation. In the page you can:

- orbit freely or switch to a top view;
- open the compact **Move robot** control and move all five arm joints;
- click any tool to place a translate/rotate gizmo on its mating flange;
- drag that flange to the wrist, attach it inside the capture range, detach it,
  and return it to its rack position.

The rack is a ten-part rounded under-slung truss rather than a collection of
solid blocks. It uses three hollow A-frame stations, separate flat-printing
T-saddles, and four removable base links. The printed assembly is 244.01 cm³,
its largest part dimension is 190.39 mm, and the generated solids are valid and
non-overlapping. Existing dock datums are retained: the gripper fastens through
the source support-head M4 centers, while spoon and whisk use two short metal
stays into their existing rear-anchor blocks. See [PRINTING.md](PRINTING.md) for
the generated parts, hardware, and assembly notes.

The geometry has passed digital checks, including a 486-sample sweep across the
parked-to-approach and approach-to-seat paths for all three tools with zero
fixture or adapter contacts. This is not a structural load rating or physical
qualification; print and bench-test one station before relying on the complete
rack.

The deployed owner-only build is at
[quickattach-control.janos95.chatgpt.site](https://quickattach-control.janos95.chatgpt.site).

## Browser automation and rendering

The browser exposes a deterministic `window.quickAttach` API:

`getState`, `setState`, `setJoint`, `setPreset`, `setTool`, `selectTool`,
`setGizmoMode`, `getAttachmentError`, `attachSelected`, `releaseAttached`,
`returnSelectedToRack`, `moveToDock`, `step`, `reset`, `resetCamera`,
`topCamera`, and `renderFrame`.

Add `?headless=1` to show only the render surface.
`scripts/render-threejs-video.py` drives this API from Python Playwright,
captures fixed-size frames, and encodes them with FFmpeg. Three.js is therefore
the shared visual layer for the interactive page and headless video, while
MuJoCo/Python remain the numerical validation authority.

## Regenerating the model bundle

The exporter imports the source model from this QuickAttach checkout, builds
the printable rack with CadQuery, and writes the browser-ready MJCF, assets,
and manifests to `public/model/`.

```bash
XDG_CACHE_HOME=/tmp/quickattach-cache \
../../.venv/bin/python scripts/export-matcha-model.py --output public/model
```

## Development

Requires Node.js `>=22.13.0`.

```bash
npm run install:ci
npm run dev
npm run lint
npm test
```

The app is a vinext site. Source lives under `app/`; generated model assets live
under `public/model/`. `npm test` builds, validates the deployment artifact, and
checks rendered preview metadata.

## Rendering the video

Start the same page on a fixed local port:

```bash
npm run dev -- --port 4173
```

Then drive its public browser API from another terminal:

```bash
python3 scripts/render-threejs-video.py \
  --url http://127.0.0.1:4173/ \
  --output outputs/quickattach-threejs-workflow.mp4
```

Python Playwright, its Chromium browser, and FFmpeg must be installed. The
renderer captures the exact interactive Three.js scene; there is no separate
video-only renderer or scene definition.

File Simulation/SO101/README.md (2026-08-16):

# SO101 Robot - URDF and MuJoCo Description

> Modified for QuickAttach: box-stacking demo instructions were added to the
> upstream SO-101 simulation documentation.

This repository contains the URDF and MuJoCo (MJCF) files for the SO101 robot.

## Overview

- The robot model files were generated using the [onshape-to-robot](https://github.com/Rhoban/onshape-to-robot) plugin from a CAD model designed in Onshape.
- The generated URDFs were modified to allow meshes with relative paths instead of `package://...`.
- Base collision meshes were removed due to problematic collision behavior during simulation and planning.

## Calibration Methods

The MuJoCo file `scene.xml` supports two differenly calibrated SO101 robot files:

- **New Calibration (Default)**: Each joint's virtual zero is set to the **middle** of its joint range. Use -> `so101_new_calib.xml`. 
- **Old Calibration**: Each joint's virtual zero is set to the configuration where the robot is **fully extended horizontally**. Use -> `so101_old_calib.xml`.

To switch between calibration methods, modify the included robot file in `scene.xml`.

## Motor Parameters

Motor properties for the STS3215 motors used in the robot are adapted from the [Open Duck Mini project](https://github.com/apirrone/Open_Duck_Mini).

## Gripper Note

In LeRobot, the gripper is represented as a **linear joint**, where:

* `0` = fully closed
* `100` = fully open

This mapping is **not yet reflected** in the current URDF and MuJoCo files. 

---

Feel free to open an issue or contribute improvements!

## Box-stacking demo

`box_stack_scene.xml` adds a work surface, two dynamic 52 mm cubes, a stack
target, and a fixed overview camera to the calibrated SO-101 model.
`box_stack_demo.py` runs a small scripted task using damped least-squares
position IK. For this first prototype, grasping is assisted by an equality weld
that activates only after the jaw closes near a cube. Cube/table/stack contacts
remain physical. This makes the task deterministic while leaving the end
effector geometry easy to replace later.

From the repository root:

```bash
python3 -m venv .venv
.venv/bin/pip install -r Simulation/SO101/requirements.txt
.venv/bin/python Simulation/SO101/box_stack_demo.py
```

For CI or machines without a display:

```bash
.venv/bin/python Simulation/SO101/box_stack_demo.py --headless
```

The process exits with status 0 when both cubes finish inside the target stack
tolerance. Use `--save-preview Simulation/SO101/box_stack_preview.png` with an
off-screen OpenGL backend such as `MUJOCO_GL=egl` to capture the final frame.

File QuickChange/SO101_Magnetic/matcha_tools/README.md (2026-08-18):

# SO-101 matcha tools

This package is the CAD authority for two food-task end effectors on the
powered SO-101 magnetic quick changer:

| Tool | Fixed tool ID | TTL bus address | Working element |
|---|---:|---:|---|
| Matcha dose spoon | 21 | none | 0.70-0.85 mL stainless dosing cup |
| Actuated matcha whisk | 22 | 7 | eccentric-drive replaceable brush |

The existing stock gripper remains the third tool, but stays on the separate
core quick-change dock and stock-adapter package.  This add-on rack has only
`spoon` and `whisk` bays at 96 mm pitch.  That boundary is intentional: the
recovered official fixed-body STEP does not include the moving jaw, so this
keeper must not be presented as exact authority for the whole gripper.

## Geometry authority

`generate_matcha_tool_cad.py` imports `../generate_cad.py` and calls
`tool_plate(stock_gripper=False)` directly.  It does not redraw the coupling.
Consequently the target pockets, tapered locator sockets, tangential relief,
positive-lock studs, contact-board recess, four tool-mount holes, and all face
datums remain the exact generic interface.

Every rigid interface item is a separate named solid:

- two MC-12-12-03 targets, two ISO 10642 M5x10 screws, and two DIN 934 M5 nuts;
- two McMaster 90318A720 shoulder screws and two DIN 934 M3 captive nuts;
- the 10 x 22 x 1 mm FR-4 target board and all four copper pads.

This naming is intentional: simulation conversion must create collision
geometry for the screws, nuts, targets, PCB, pads, carriers, actuator parts,
and working elements.  A visual-only assembly mesh is not an acceptable
collision replacement.

## Spoon

The spoon uses a centred 3.2 mm stainless stem retained by two opposed M3 set
screws.  Its shallow elliptical cup opens sideways, so the robot can scoop
powder without the tool shaft entering the canister.  The calculated cavity is
about 0.75 mL; powder dose still has to be calibrated by mass because packing
and humidity dominate a volumetric estimate.

## Whisk

The whisk source includes a 25 mm 12 V motor envelope, shaft, balanced
eccentric rotor, 4 mm crank pin, X carriage, axial compliance carriage and
spring, splash bellows, removable brush hub, individual bamboo-bristle solids,
and the bus-driver PCB.  The compliance stroke is 5.10 mm with authored limits
`[-5.05, +0.05] mm`.  The brush has a separate conservative collision envelope;
that envelope is marked `fabrication=false` and has zero mass, so it cannot be
mistaken for solid bamboo in the mass ledger.

The motor and driver masses are explicit design inputs (72 g and 8 g), not
densities inferred from their outer envelopes.  A finished tool must be
weighed and its measured COM/inertia substituted before controller tuning.

## Mass and balance

Each ledger publishes every component's volume, density or mass override,
centre of mass, and inertia about its own COM.  Assembly inertia is recomputed
with the parallel-axis theorem.  A computed steel slug in the right-side
carrier pocket cancels the electrical wing and PCB's negative-X moment.  The
focused test requires the resulting X/Y COM magnitude to be at most 0.05 mm.

PA12, FR-4, bamboo, silicone and electronics densities are clearly labelled as
design assumptions.  They are useful for dry-run dynamics, not fabrication
certificates.

## Rack status

The source includes a two-bay matcha rack with 0.50 mm wall clearance and 0.30 mm
rear-face clearance around the complete spoon and whisk envelopes.  The left
lower rail ends 0.30 mm outboard of the FR-4 board, preventing the board edge
from becoming a support land. Lower
ledges are tangent to the coupling face; upper ledges act only on the plate's
outer lands. The passive lock cam stays below the tool face and acts on the
robot-side slider. Both bays call the core generator's complete
`positive_lock_cam()` directly, including its axial lead, hold finger, root
bridge and rack-exit wedge; the matcha generator carries no shifted polygon or
second cam approximation. The same executable cam contract is stored in the
matcha manifest.

Each bay publishes its exact stop contract in the canonical manifest. In the
bay-local frame the stop bounds are `X[-41,33]`, `Y[25,31]`,
`Z[-3,12.5]` mm; the spoon and whisk records add their respective rack-X
offsets. These are intentionally distinct from the separate core stock-gripper
dock bounds and must remain distinct in simulation.

The gripper is not a reserved matcha-rack bay.  Its existing core adapter,
passive dock, retrofit assembly and moving-jaw mesh are hash-pinned in the
matcha report as an external scope boundary.  The report makes no claim that
the spoon/whisk keeper profile fits the gripper overhang.

## Seconds-scale source checks

From the repository root, after installing `Simulation/SO101/requirements.txt`:

```bash
XDG_CACHE_HOME=/tmp/cq-cache .venv/bin/python \
  QuickChange/SO101_Magnetic/matcha_tools/test_matcha_tool_cad.py
```

The focused test checks fixed IDs, exact common-plate and complete core-cam
identity, the complete
15-solid interface-hardware roster, unique component inventories, balance and
inertia arithmetic, spoon capacity, and rack source structure.  It is not an
exact swept-interference release test.

The rack preflight is also seconds-scale:

```bash
XDG_CACHE_HOME=/tmp/cq-cache .venv/bin/python \
  QuickChange/SO101_Magnetic/matcha_tools/validate_matcha_rack.py --preflight
XDG_CACHE_HOME=/tmp/cq-cache .venv/bin/python \
  QuickChange/SO101_Magnetic/matcha_tools/test_matcha_rack_validation.py
```

It closes every named spoon/whisk component against every rack component,
including adjacent bays and all seven whisk mechanism extrema.  The fast path
uses a rigorous continuous swept-AABB lower bound.  Only the six exact named
plate/ledge and plate/stop tangencies use an FCPW mesh screen followed by OCCT
B-rep distance and overlap-volume diagnostics.  FCPW is screening evidence,
not STEP clearance authority.  This report covers only the two matcha bays;
normal-gripper release remains the responsibility of the separate core
quick-change package.

## Reproducible exports

`generate_matcha_tool_cad.py` canonicalizes OCCT's wall-clock STEP header and
accepts `--output-dir`, so byte reproducibility can be checked in two temporary
directories without modifying the checked-in package.  The canonical run is:

```bash
XDG_CACHE_HOME=/tmp/cq-cache .venv/bin/python \
  QuickChange/SO101_Magnetic/matcha_tools/generate_matcha_tool_cad.py
XDG_CACHE_HOME=/tmp/cq-cache .venv/bin/python \
  QuickChange/SO101_Magnetic/matcha_tools/validate_matcha_rack.py --release-report
```

The single `exports/matcha_tool_manifest.json` records repo-relative paths,
roles, byte counts, and SHA-256 digests for all ten CAD/ledger artifacts.  The
rack report pins that manifest and independently recomputes the full collision
inventory.  It does not hash itself or create a circular manifest dependency.

Generated STEP/STL assemblies, JSON ledgers, the single canonical hash-pinned
`exports/matcha_tool_manifest.json`, and the exact rack-sweep report form one
release package. Any source or contract change makes those artifacts stale;
fabrication remains blocked until deterministic regeneration, manifest hash
closure, and the exact rack report all pass together.

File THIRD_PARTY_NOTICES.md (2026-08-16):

# Third-party notices

## TheRobotStudio/SO-ARM100

QuickAttach uses SO-101 model assets from
[TheRobotStudio/SO-ARM100](https://github.com/TheRobotStudio/SO-ARM100) at
commit [`7629d2ad9853d10fb903093a33ef6114099d97e5`](https://github.com/TheRobotStudio/SO-ARM100/commit/7629d2ad9853d10fb903093a33ef6114099d97e5).

The upstream project is licensed under the Apache License 2.0. A copy of that
license is included as `LICENSE` in this repository. The upstream citation
metadata is available in its
[`CITATION.cff`](https://github.com/TheRobotStudio/SO-ARM100/blob/7629d2ad9853d10fb903093a33ef6114099d97e5/CITATION.cff).

Upstream or upstream-derived material in this repository includes:

- `Simulation/SO101/assets/*.stl`
- `Simulation/SO101/joints_properties.xml`
- `Simulation/SO101/scene.xml`
- `Simulation/SO101/so101_new_calib.xml` and `.urdf`
- `Simulation/SO101/so101_old_calib.xml` and `.urdf`
- `Simulation/SO101/README.md`, with QuickAttach demo instructions added
- `STEP/SO101/Follower_Specific/Wrist_Roll_Follower_SO101.step`
- stock-gripper geometry embedded in the generated retrofit assembly STEP

QuickAttach-specific controller code, task scenes, quick-changer CAD source,
and generated quick-changer parts are modifications or additions created for
this project.

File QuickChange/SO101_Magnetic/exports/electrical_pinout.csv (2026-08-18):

pin | target_x_mm | wire_x_mm | y_mm | signal | stock_gripper_use | notes
1 | -1.0 | 3.5 | -7.5 | GND | yes | nominal first-mate/last-break datum only; tolerance stack unqualified; official Feetech pin 1
2 | -1.0 | 3.5 | -2.5 | +12V | yes | official Feetech pin 2
3 | -1.0 | 3.5 | 2.5 | TTL_DATA | yes | official Feetech pin 3, half-duplex TTL
4 | -1.0 | 3.5 | 7.5 | TOOL_ID_SPARE | no | optional tool ID/detect; unused by stock three-wire gripper

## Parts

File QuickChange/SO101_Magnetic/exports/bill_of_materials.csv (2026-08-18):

assembly | quantity | part | specification | source | status_or_note
robot | 1 | so101_robot_plate | printed PA12/PA-CF part | exports/so101_robot_plate.step | new
robot | 2 | CS-Q-12-12-04-N | 12x12x4 mm N35 screw-on magnet | https://www.supermagnete.de/eng/screw-on-neodymium-magnets/screw-on-block-magnet-12-x-12-x-4mm_CS-Q-12-12-04-N | new
robot | 2 | ISO 10642 M3x10 | countersunk screw for magnet | standard fastener | new
robot | 2 | DIN 934 M3 | nut for magnet screw | standard fastener | new
robot | 4 | M3x10 socket-head | robot plate to existing wrist horn | standard fastener | new; verify engagement/no bottoming
robot | 1 | 304 stainless lock slider | 1.5-1.6 mm sheet | exports/so101_positive_lock_slider_profile.dxf | new; STL is fit-check only
robot | 1 | E-GUL4-10 | OD4 x L10 mm, 0.98 N/mm return spring | https://us.misumi-ec.com/vona2/detail/110310903689/?HissuCode=E-GUL4-10 | new
robot | 1 | M2x6 flat-head | slider guide/retainer | standard fastener | new
robot | 4 | 7983-1-15-20-75-14-11-0 | high-current solder-cup spring pin | https://www.mill-max.com/products/discrete-spring-loaded-pins/spring-loaded-pin-with-solder-cup-termination/7983/7983-1-15-20-75-14-11-0 | knurl/solder-cup-first sectional mount; fit, pull-out, first-mate tolerance, and cycle reliability unqualified
tool | 1 | so101_stock_gripper_tool_plate | printed PA12/PA-CF part | exports/so101_stock_gripper_tool_plate.step | new
tool | 2 | MC-12-12-03 | 12x12x3 mm Q235 steel magnet target | https://www.supermagnete.de/eng/magnet-counterparts-to-screw-on/metal-plates-with-countersunk-hole-12-x-12-x-3mm_MC-12-12-03 | new
tool | 2 | ISO 10642 M5x10 | countersunk screw for steel target | standard fastener | new
tool | 2 | DIN 934 M5 | rear captive nut for steel target | standard fastener | new
tool | 2 | McMaster 90318A720 | M3; 4 mm dia x 5 mm shoulder pull stud | https://www.mcmaster.com/90318A720/ | new
tool | 2 | DIN 934 M3 | rear captive pull-stud nut, 5.5 AF x 2.4 | https://accu-components.com/us/hexagon-nuts/7888-HPN-M3-A2 | new
tool | 1 | SO101 target PCB | 10x22x1.0 mm FR-4, 2 oz, ENIG | exports/tool_contact_board.kicad_pcb | fabricate
gripper retrofit | 4 | Ruthex RX-M3x5.7 | heat-set insert | https://www.ruthex.de/en/products/ruthex-gewindeeinsatz-m3-100-stuck-rx-m3x5-7-messing-gewindebuchsen | new
gripper retrofit | 4 | M3x6 | stock gripper to detachable tool plate | standard fastener | reuse original
gripper retrofit | 1 | 3-wire adapter harness | GND/+12V/TTL; mating stock connectors | electrical_pinout.csv | new; do not cut stock arm harness
dock | 1 | so101_passive_tool_dock | printed PA12/PA-CF part | exports/so101_passive_tool_dock.step | new
dock | 1 | so101_core_dock_support_bracket | printed PA12/PA-CF floor pedestal | exports/so101_core_dock_support_bracket.step | source checkpoint; do not fabricate before blockers close
dock | 2 | ISO 10642 M4x25 A2 | stop-to-support countersunk screw | standard/vendor authority pending | blocked
dock | 2 | DIN 125 M4 + DIN 985 M4 | washer and locknut for support head | standard/vendor authority pending | blocked
dock | 4 | ISO 10642 M6x20 | support-to-tapped-fixture countersunk screw | standard/vendor and fixture-substrate authority pending | blocked

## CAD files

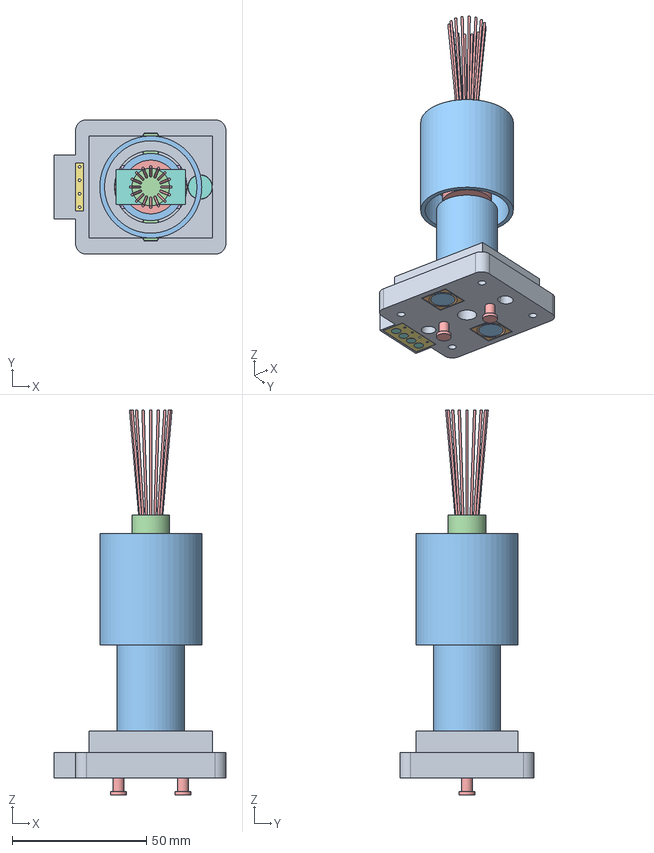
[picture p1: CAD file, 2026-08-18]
QuickChange/SO101_Magnetic/matcha_tools/exports/so101_matcha_whisk_tool_assembly.step
64.0 x 50.0 x 143.3 mm
common_tool_plate
target_1_MC-12-12-03
target_screw_1_ISO10642_M5x10
target_nut_1_DIN934_M5
target_2_MC-12-12-03
target_screw_2_ISO10642_M5x10
target_nut_2_DIN934_M5
shoulder_lock_stud_1_McMaster_90318A720
lock_stud_nut_1_DIN934_M3
shoulder_lock_stud_2_McMaster_90318A720
lock_stud_nut_2_DIN934_M3
tool_contact_board_FR4
target_pad_P1_GND
target_pad_P2_+12V
target_pad_P3_TTL_DATA
target_pad_P4_TOOL_ID_SPARE
whisk_printed_carrier
whisk_motor_12V_envelope
whisk_motor_shaft
whisk_eccentric_rotor
whisk_eccentric_pin
whisk_rotor_counterweight
whisk_carriage_x
whisk_compliance_carriage
whisk_compliance_spring
whisk_food_grade_bellows
whisk_brush_hub
whisk_bamboo_bristles
whisk_bus_driver_board
tool_id_22_resistor_0603
whisk_balance_slug_steel

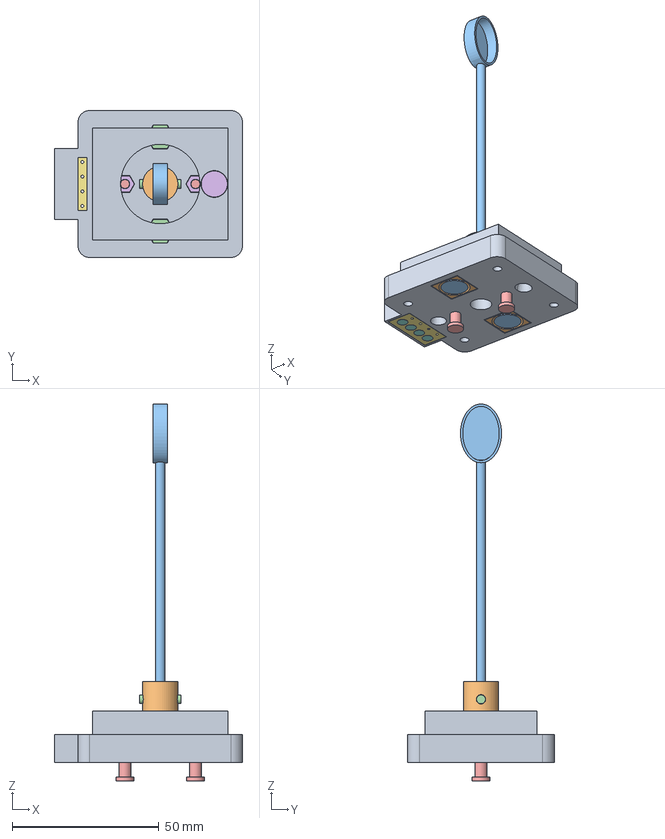
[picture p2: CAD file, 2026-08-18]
QuickChange/SO101_Magnetic/matcha_tools/exports/so101_matcha_spoon_tool_assembly.step
64.0 x 50.0 x 128.3 mm
common_tool_plate
target_1_MC-12-12-03
target_screw_1_ISO10642_M5x10
target_nut_1_DIN934_M5
target_2_MC-12-12-03
target_screw_2_ISO10642_M5x10
target_nut_2_DIN934_M5
shoulder_lock_stud_1_McMaster_90318A720
lock_stud_nut_1_DIN934_M3
shoulder_lock_stud_2_McMaster_90318A720
lock_stud_nut_2_DIN934_M3
tool_contact_board_FR4
target_pad_P1_GND
target_pad_P2_+12V
target_pad_P3_TTL_DATA
target_pad_P4_TOOL_ID_SPARE
spoon_printed_carrier
spoon_stainless_insert
spoon_set_screw_x_minus_M3x6
spoon_set_screw_x_plus_M3x6
tool_id_21_resistor_0603
spoon_balance_slug_steel

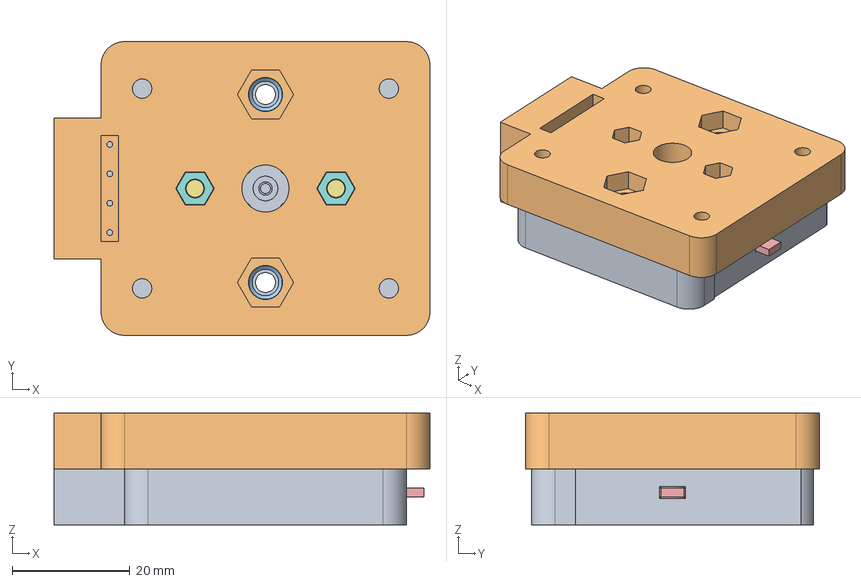
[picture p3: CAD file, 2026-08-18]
QuickChange/SO101_Magnetic/exports/so101_quick_change_assembly.step
64.0 x 50.0 x 19.0 mm
robot_plate
generic_tool_plate
magnet_1_CS-Q-12-12-04-N x 2
target_1_MC-12-12-03 x 2
positive_lock_slider_locked
return_spring_E-GUL4-10
shoulder_lock_stud_1_McMaster_90318A720
lock_stud_nut_1_DIN934_M3
shoulder_lock_stud_2_McMaster_90318A720
lock_stud_nut_2_DIN934_M3
P1_GND_7983-1-15-20-75-14-11-0 x 4
tool_contact_board_FR4
target_pad_P1_GND x 4

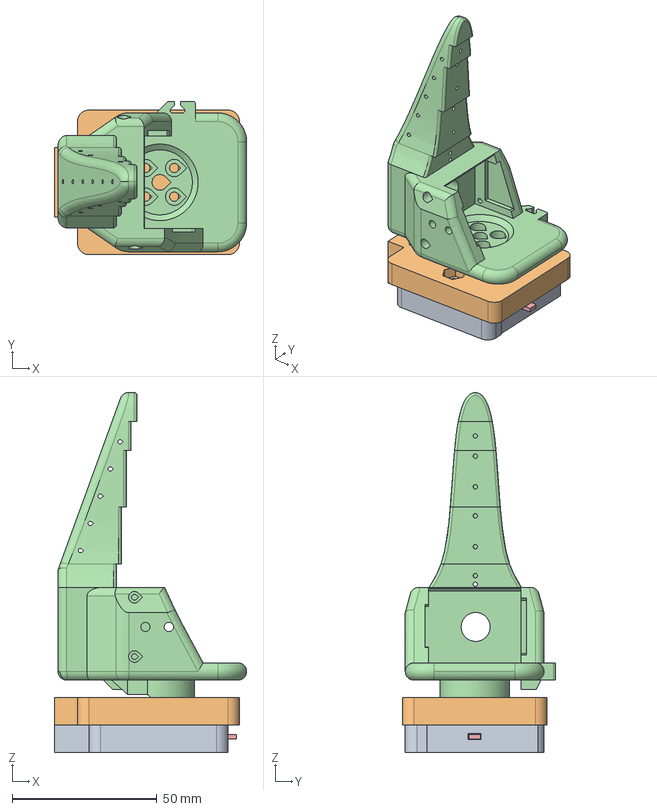
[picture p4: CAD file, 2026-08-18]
QuickChange/SO101_Magnetic/exports/so101_stock_gripper_retrofit_assembly.step
66.5 x 53.0 x 124.4 mm
robot_plate
stock_gripper_tool_plate
magnet_1_CS-Q-12-12-04-N x 2
target_1_MC-12-12-03 x 2
positive_lock_slider_locked
return_spring_E-GUL4-10
shoulder_lock_stud_1_McMaster_90318A720
lock_stud_nut_1_DIN934_M3
shoulder_lock_stud_2_McMaster_90318A720
lock_stud_nut_2_DIN934_M3
P1_GND_7983-1-15-20-75-14-11-0 x 4
tool_contact_board_FR4
target_pad_P1_GND x 4
official_stock_gripper_body_reference

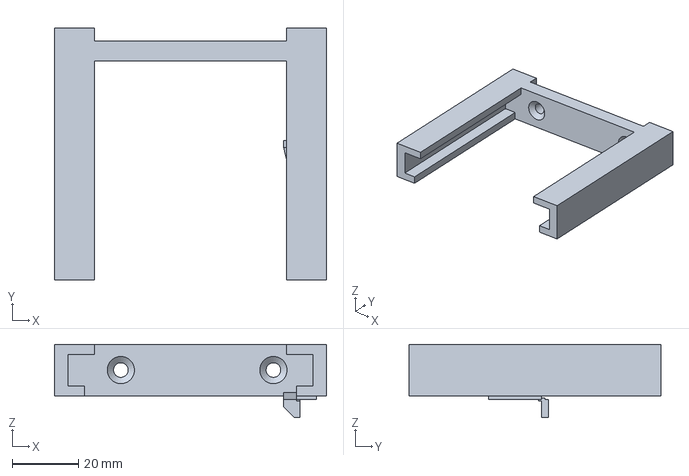
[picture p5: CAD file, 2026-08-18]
QuickChange/SO101_Magnetic/exports/so101_passive_tool_dock.step
82.0 x 76.0 x 22.1 mm

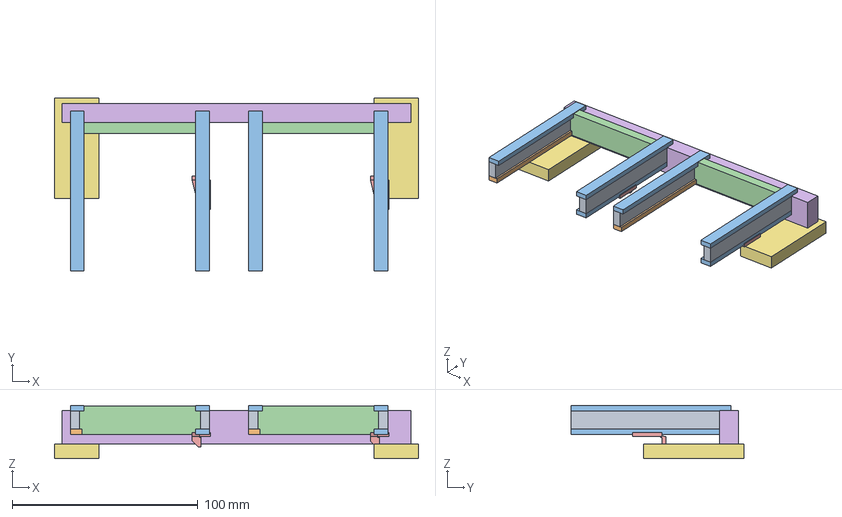
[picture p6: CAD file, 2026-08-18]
QuickChange/SO101_Magnetic/matcha_tools/exports/so101_matcha_two_bay_rack.step
196.0 x 93.0 x 28.8 mm

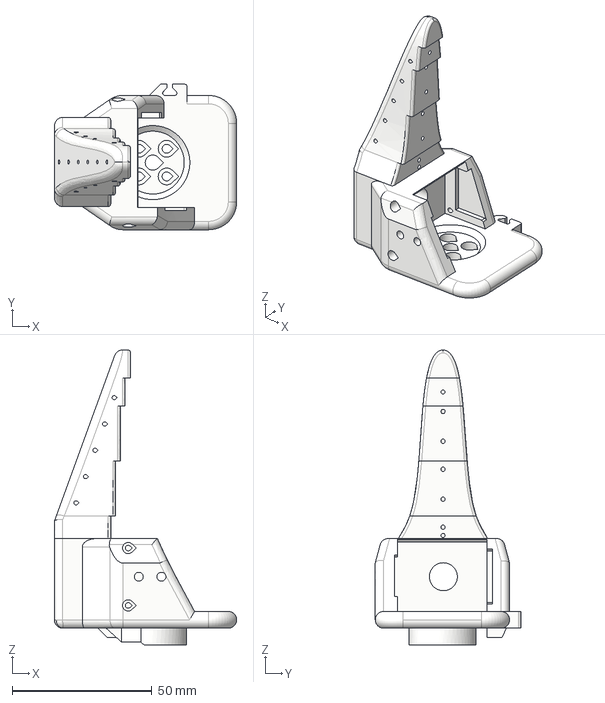
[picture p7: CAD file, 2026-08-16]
STEP/SO101/Follower_Specific/Wrist_Roll_Follower_SO101.step
65.2 x 52.0 x 105.4 mm
Wiring_holder v1
Wiring_holder v1 (1)

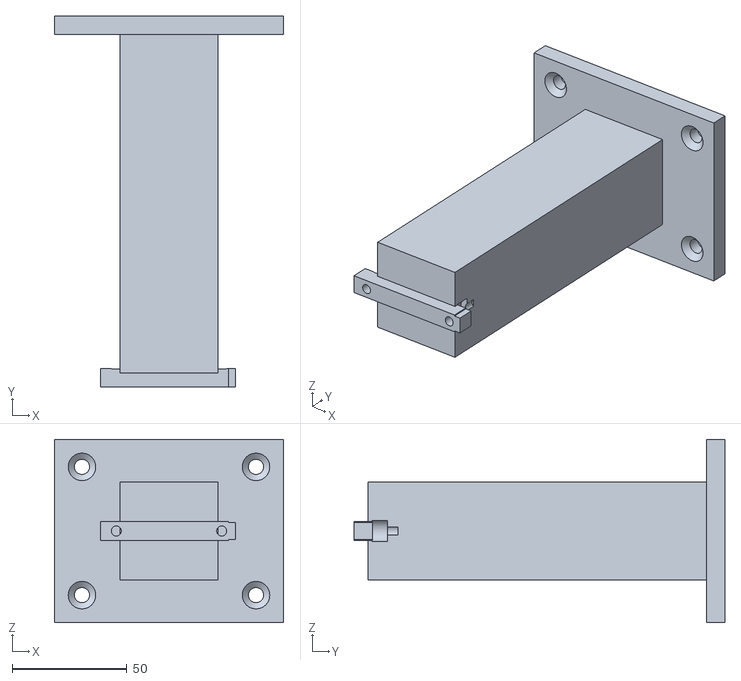
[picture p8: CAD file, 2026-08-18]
web/quickattach-control/public/model/cad/dock-support-bracket.stl
100.0 x 161.9 x 80.0

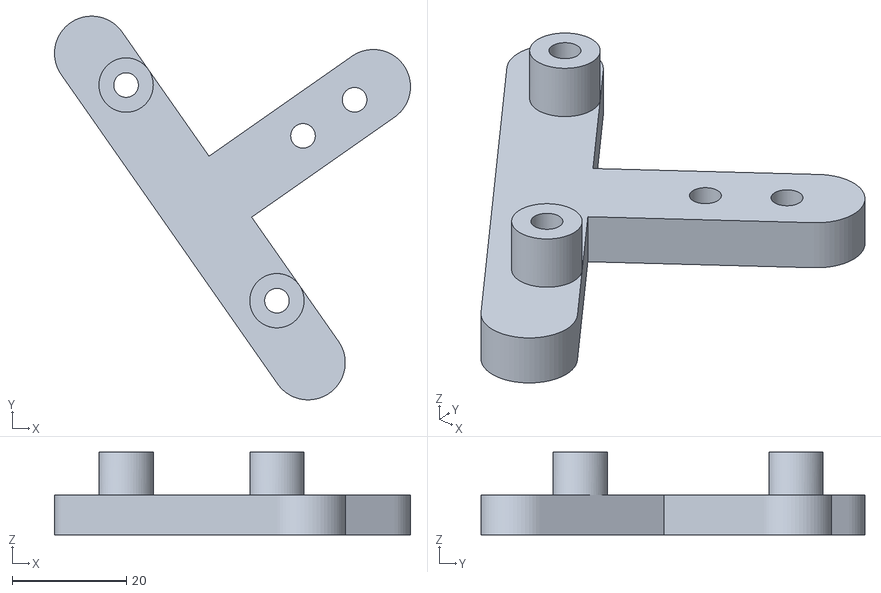
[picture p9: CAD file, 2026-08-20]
web/quickattach-control/public/model/printable_fixture_saddle_gripper.stl
62.2 x 67.1 x 14.5

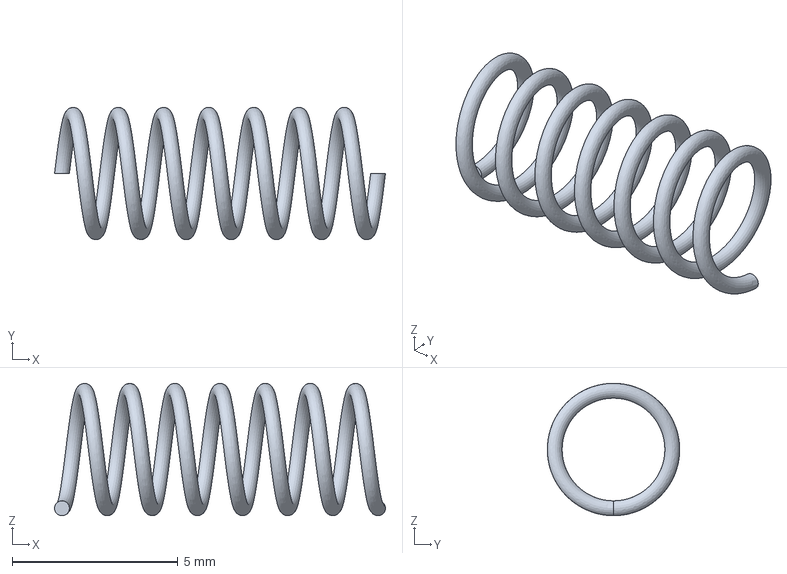
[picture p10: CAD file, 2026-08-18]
QuickChange/SO101_Magnetic/exports/hardware_E-GUL4-10_reference.step
10.00 x 4.00 x 4.00 mm

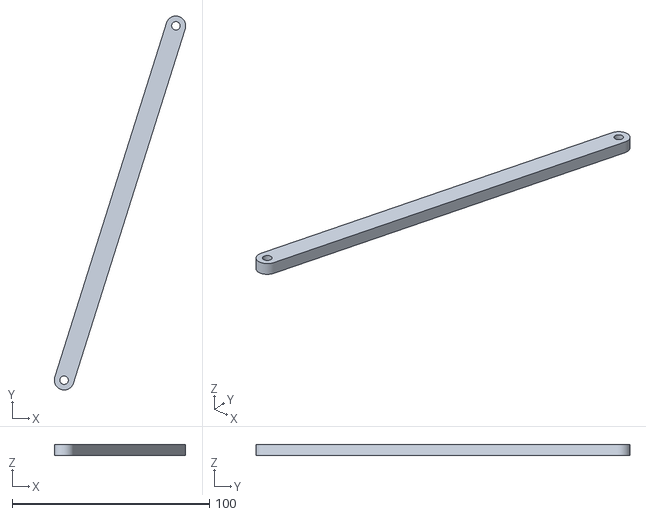
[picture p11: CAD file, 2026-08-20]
web/quickattach-control/public/model/printable_fixture_rear_spoon_whisk.stl
66.7 x 189.8 x 5.50

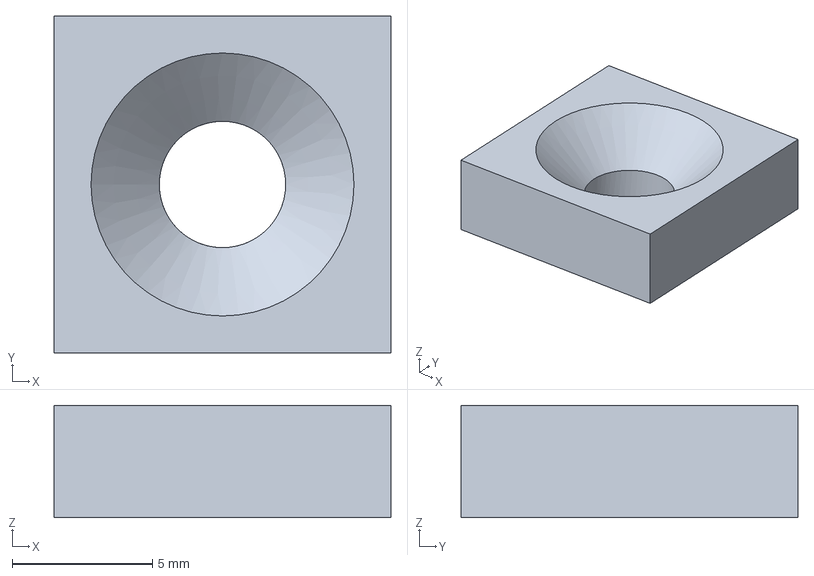
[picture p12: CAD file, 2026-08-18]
QuickChange/SO101_Magnetic/exports/hardware_CS-Q-12-12-04-N.step
12.0 x 12.0 x 4.00 mm

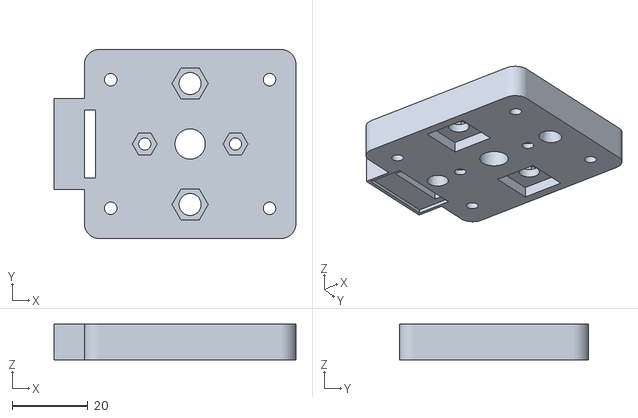
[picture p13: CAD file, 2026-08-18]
web/quickattach-control/public/model/cad/generic-tool-plate.stl
64.0 x 50.0 x 9.50

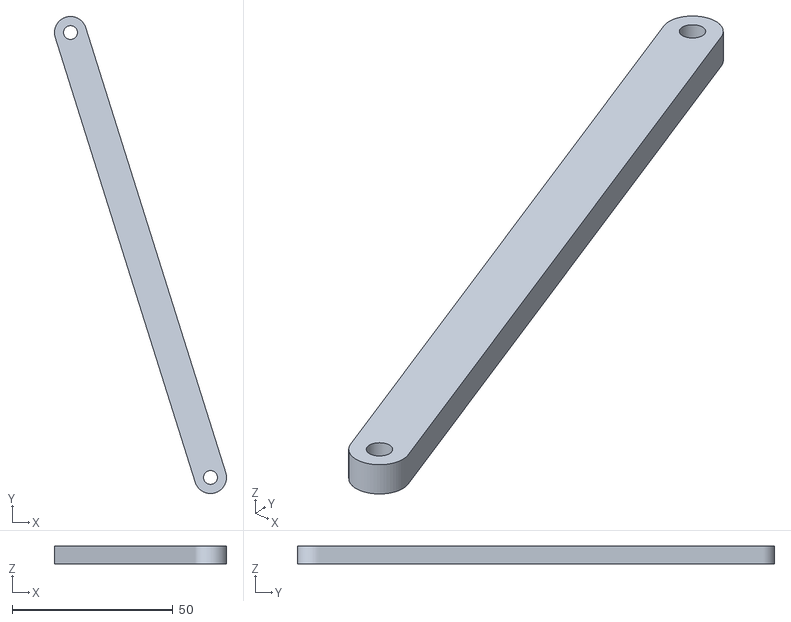
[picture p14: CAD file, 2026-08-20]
web/quickattach-control/public/model/printable_fixture_front_gripper_spoon.stl
53.6 x 148.5 x 5.50

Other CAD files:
web/quickattach-control/public/model/cad/passive-tool-dock.stl
QuickChange/SO101_Magnetic/exports/so101_stock_gripper_tool_plate.step
QuickChange/SO101_Magnetic/matcha_tools/exports/so101_matcha_spoon_printed_body.step
web/quickattach-control/public/model/cad/gripper-tool-plate.stl
QuickChange/SO101_Magnetic/exports/hardware_DIN934_M3_lock_stud_nut.step
QuickChange/SO101_Magnetic/exports/hardware_MC-12-12-03.step
QuickChange/SO101_Magnetic/exports/hardware_McMaster_90318A720_shoulder_screw.step
QuickChange/SO101_Magnetic/exports/hardware_Mill-Max_7983-1-15-20-75-14-11-0_reference.step
QuickChange/SO101_Magnetic/exports/so101_core_dock_support_bracket.step
QuickChange/SO101_Magnetic/exports/so101_positive_lock_slider.step
QuickChange/SO101_Magnetic/exports/so101_positive_lock_slider_profile.dxf
QuickChange/SO101_Magnetic/exports/so101_robot_plate.step
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

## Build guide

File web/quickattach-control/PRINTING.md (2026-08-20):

# Printable tool rack

The generated rack is a modular, rounded, under-slung truss designed to keep the
robot's approach corridor open while giving every load a continuous path to the
bench. All dimensions below come from
`public/model/printable_fixture_manifest.json`.

## Parts

| Quantity | Part | Print orientation |
| ---: | --- | --- |
| 1 each | `station_gripper`, `station_spoon`, `station_whisk` | Upright on the rounded feet; support the short crown cantilever |
| 1 each | `saddle_gripper`, `saddle_spoon`, `saddle_whisk` | Flat, with dock bosses upward |
| 1 each | two front and two rear link bars | Broad face on the bed |

The ten STL files are under `public/model/`. The largest envelope is
190.39 × 66.76 × 5.5 mm. Total modeled printed volume is 244.01 cm³. The
generator checks that every part is one valid solid and that assembled printed
parts do not intersect.

## Hardware

- 6 × M5 bench fasteners, plus bench-appropriate washers and anchors
- M4 screws for the 8 base-link joints and 6 saddle joints
- M4 screws and heat-set inserts for the dock interfaces
- 0.75 mm washers between station feet and link bars
- 0.5 mm washers between each station crown and saddle
- 2 × short 3.5 mm metal stays for the spoon dock and 2 × for the whisk dock

Select screw lengths after measuring the printed parts, washer stack, insert
depth, and retained source adapter. No screw may protrude into a tool or flange
envelope.

## Assembly

1. Print and deburr all holes. Install heat-set inserts with a temperature and
   pull-out test appropriate to the chosen material.
2. Join each T-saddle to its A-frame crown using the 0.5 mm washer gap. The
   saddle must remain below the parked tool envelope.
3. Fasten the gripper dock through the two M4 centers in its retained source
   support head.
4. Connect each spoon/whisk saddle stay pad to the dock's retained rear-anchor
   block using two short metal stays. Do not substitute printed cantilevers for
   these stays.
5. Join adjacent station feet with the four link bars and 0.75 mm washers.
6. Square the assembly, then fasten all six station feet to a rigid bench.
7. Move the unpowered robot through each docking path by hand before enabling
   actuators. Verify screw clearance, flange access, and cable routing.

## Qualification boundary

The CAD generator and collision sweep establish geometric realizability, not
strength, fatigue life, print quality, or safe robot operation. Material,
infill, layer direction, inserts, bench anchors, and dynamic loads remain to be
qualified on physical hardware. Prototype one complete station first and use a
low-speed, current-limited commissioning pass.

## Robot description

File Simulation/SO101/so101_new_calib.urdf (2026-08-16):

<?xml version="1.0" encoding="utf-8"?>
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
<robot name="so101_new_calib">

  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
  <link name="base_link">
    <inertial>
      <origin xyz="0.0137179 -5.19711e-05 0.0334843" rpy="0 0 0"/>
      <mass value="0.147"/>
      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
    </inertial>
    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
  </link>

  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
  <link name="shoulder_link">
    <inertial>
      <origin xyz="-0.0307604 -1.66727e-05 -0.0252713" rpy="0 0 0"/>
      <mass value="0.100006"/>
      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
    </inertial>
    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
  </link>

  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
  <link name="upper_arm_link">
    <inertial>
      <origin xyz="-0.0898471 -0.00838224 0.0184089" rpy="0 0 0"/>
      <mass value="0.103"/>
      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
    </inertial>
    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
  </link>

  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
  <link name="lower_arm_link">
    <inertial>
      <origin xyz="-0.0980701 0.00324376 0.0182831" rpy="0 0 0"/>
      <mass value="0.104"/>
      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
    </inertial>
    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
  </link>

  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
  <link name="wrist_link">
    <inertial>
      <origin xyz="-0.000103312 -0.0386143 0.0281156" rpy="0 0 0"/>
      <mass value="0.079"/>
      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
    </inertial>
    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
  </link>

  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
  <link name="gripper_link">
    <inertial>
      <origin xyz="0.000213627 0.000245138 -0.025187" rpy="0 0 0"/>
      <mass value="0.087"/>
      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
    </inertial>
    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
  </link>

  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
  <link name="gripper_frame_link">
    <origin xyz="0 0 0" rpy="0 -0 0"/>
    <inertial>
      <origin xyz="0 0 0" rpy="0 0 0"/>
      <mass value="1e-9"/>
      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
    </inertial>
  </link>

  <joint name="gripper_frame_joint" type="fixed">
    <origin xyz="-0.0079 -0.000218121 -0.0981274" rpy="0 3.14159 0"/>
    <parent link="gripper_link"/>
    <child link="gripper_frame_link"/>
    <axis xyz="0 0 0"/>
  </joint>

  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
  <link name="moving_jaw_so101_v1_link">
    <inertial>
      <origin xyz="-0.00157495 -0.0300244 0.0192755" rpy="0 0 0"/>
      <mass value="0.012"/>
      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
    </inertial>
    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
  </link>

  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
  <joint name="gripper" type="revolute">
    <origin xyz="0.0202 0.0188 -0.0234" rpy="1.5708 -5.24284e-08 -1.41553e-15"/>
    <parent link="gripper_link"/>
    <child link="moving_jaw_so101_v1_link"/>
    <axis xyz="0 0 1"/>
    <limit effort="10" velocity="10" lower="-0.174533" upper="1.74533"/>
  </joint>

  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
  <joint name="wrist_roll" type="revolute">
    <origin xyz="5.55112e-17 -0.0611 0.0181" rpy="1.5708 0.0486795 3.14159"/>
    <parent link="wrist_link"/>
    <child link="gripper_link"/>
    <axis xyz="0 0 1"/>
    <limit effort="10" velocity="10" lower="-2.74385" upper="2.84121"/>
  </joint>

  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
  <joint name="wrist_flex" type="revolute">
    <origin xyz="-0.1349 0.0052 3.62355e-17" rpy="4.02456e-15 8.67362e-16 -1.5708"/>
    <parent link="lower_arm_link"/>
    <child link="wrist_link"/>
    <axis xyz="0 0 1"/>
    <limit effort="10" velocity="10" lower="-1.65806" upper="1.65806"/>
  </joint>

  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
  <joint name="elbow_flex" type="revolute">
    <origin xyz="-0.11257 -0.028 1.73763e-16" rpy="-3.63608e-16 8.74301e-16 1.5708"/>
    <parent link="upper_arm_link"/>
    <child link="lower_arm_link"/>
    <axis xyz="0 0 1"/>
    <limit effort="10" velocity="10" lower="-1.69" upper="1.69"/>
  </joint>

  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
  <joint name="shoulder_lift" type="revolute">
    <origin xyz="-0.0303992 -0.0182778 -0.0542" rpy="-1.5708 -1.5708 0"/>
    <parent link="shoulder_link"/>
    <child link="upper_arm_link"/>
    <axis xyz="0 0 1"/>
    <limit effort="10" velocity="10" lower="-1.74533" upper="1.74533"/>
  </joint>

  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
  <joint name="shoulder_pan" type="revolute">
    <origin xyz="0.0388353 -8.97657e-09 0.0624" rpy="3.14159 4.18253e-17 -3.14159"/>
    <parent link="base_link"/>
    <child link="shoulder_link"/>
    <axis xyz="0 0 1"/>
    <limit effort="10" velocity="10" lower="-1.91986" upper="1.91986"/>
  </joint>

  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 

</robot>

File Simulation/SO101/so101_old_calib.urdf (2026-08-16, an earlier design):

<?xml version='1.0' encoding='utf-8'?>
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
<robot name="so101_old_calib">

  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
  <link name="base">
    <inertial>
      <origin xyz="0.020739 0.00204287 0.065966" rpy="0 0 0"/>
      <mass value="0.147"/>
      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
    </inertial>
    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
  </link>

  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
  <link name="shoulder">
    <inertial>
      <origin xyz="-0.0307604 -1.66727e-05 -0.0252713" rpy="0 0 0"/>
      <mass value="0.100006"/>
      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
    </inertial>
    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
  </link>

  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
  <link name="upper_arm">
    <inertial>
      <origin xyz="-0.00838224 0.0898471 0.0184089" rpy="0 0 0"/>
      <mass value="0.103"/>
      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
    </inertial>
    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
  </link>

  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
  <link name="lower_arm">
    <inertial>
      <origin xyz="-0.00324376 -0.0980701 0.0182831" rpy="0 0 0"/>
      <mass value="0.104"/>
      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
    </inertial>
    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
  </link>

  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
  <link name="wrist">
    <inertial>
      <origin xyz="-0.000103312 -0.0386143 0.0281156" rpy="0 0 0"/>
      <mass value="0.079"/>
      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
    </inertial>
    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
  </link>

  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
  <link name="gripper">
    <inertial>
      <origin xyz="0.000213627 0.000245138 -0.025187" rpy="0 0 0"/>
      <mass value="0.087"/>
      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
    </inertial>
    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
  </link>

  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
  <link name="jaw">
    <inertial>
      <origin xyz="-0.00157495 -0.0300244 0.0192755" rpy="0 0 0"/>
      <mass value="0.012"/>
      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
    </inertial>
    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
  </link>

  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
  <joint name="gripper" type="revolute">
    <origin xyz="0.0202 0.0188 -0.0234" rpy="1.5708 -7.91661e-17 -1.0396e-16"/>
    <parent link="gripper"/>
    <child link="jaw"/>
    <axis xyz="0 0 1"/>
    <limit effort="10" velocity="10" lower="-0.174533" upper="1.74533"/>
  </joint>

  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
  <joint name="wrist_roll" type="revolute">
    <origin xyz="2.77556e-17 -0.0611 0.0181" rpy="1.5708 -9.38083e-08 3.14159"/>
    <parent link="wrist"/>
    <child link="gripper"/>
    <axis xyz="0 0 1"/>
    <limit effort="10" velocity="10" lower="-2.79253" upper="2.79253"/>
  </joint>

  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
  <joint name="wrist_flex" type="revolute">
    <origin xyz="-0.0052 -0.1349 3.40439e-16" rpy="-1.41553e-15 4.91611e-15 7.56157e-09"/>
    <parent link="lower_arm"/>
    <child link="wrist"/>
    <axis xyz="0 0 1"/>
    <limit effort="10" velocity="10" lower="-1.65806" upper="1.65806"/>
  </joint>

  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
  <joint name="elbow_flex" type="revolute">
    <origin xyz="-0.028 0.11257 1.24466e-16" rpy="1.89432e-15 -3.22659e-15 -3.14159"/>
    <parent link="upper_arm"/>
    <child link="lower_arm"/>
    <axis xyz="0 0 1"/>
    <limit effort="10" velocity="10" lower="-0.174533" upper="3.14159"/>
  </joint>

  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
  <joint name="shoulder_lift" type="revolute">
    <origin xyz="-0.0303992 -0.0182778 -0.0542" rpy="-1.5708 1.5708 0"/>
    <parent link="shoulder"/>
    <child link="upper_arm"/>
    <axis xyz="0 0 1"/>
    <limit effort="10" velocity="10" lower="-3.31613" upper="0.174533"/>
  </joint>

  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
  <joint name="shoulder_pan" type="revolute">
    <origin xyz="0.0207909 -0.0230745 0.0948817" rpy="-3.14159 6.03684e-16 1.5708"/>
    <parent link="base"/>
    <child link="shoulder"/>
    <axis xyz="0 0 1"/>
    <limit effort="10" velocity="10" lower="-1.91986" upper="1.91986"/>
  </joint>

  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

</robot>

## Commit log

2026-08-16 Initialize SO-101 quick attachment design
2026-08-16 Add SO-101 quick changer CAD and MuJoCo demos
    [base_motor_holder_so101_v1.stl, base_so101_v2.stl, bill_of_materials.csv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]
2026-08-16 Make full-arm MuJoCo demo the primary validation
2026-08-16 Add model provenance and complete CAD source
    [Wrist_Roll_Follower_SO101.step, hardware_CS-Q-12-12-04-N.stl, hardware_DIN934_M3_lock_stud_nut.stl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]
2026-08-16 Complete full-arm attach and detach cycle
2026-08-17 test: stage validation across recovered simulation foundation
2026-08-17 feat: restore matcha tool CAD generators
2026-08-17 feat: publish canonical two-bay matcha CAD package
    [so101_matcha_spoon_printed_body.step, so101_matcha_spoon_printed_body.stl, so101_matcha_spoon_tool_assembly.step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]
2026-08-17 feat: restore exact core CAD clearance validator
2026-08-17 test: restore core CAD report validation
2026-08-17 test: publish honest core CAD clearance report
2026-08-17 fix: align runtime docks with exact CAD contracts
2026-08-17 feat: regenerate deterministic quick-change CAD package
    [hardware_CS-Q-12-12-04-N.step, hardware_DIN934_M3_lock_stud_nut.step, hardware_E-GUL4-10_reference.step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]
2026-08-17 fix: extend robot cam relief through plate
2026-08-17 chore: regenerate full-depth cam relief CAD
    [so101_quick_change_assembly.step, so101_robot_plate.step, so101_robot_plate.stl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]
2026-08-17 chore: regenerate corrected keyhole CAD
    [so101_positive_lock_slider.step, so101_positive_lock_slider.stl, so101_positive_lock_slider_profile.dxf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]
2026-08-17 feat: add certified STEP plate proxy authority
2026-08-17 feat: refine STEP plate proxy boundary coverage
2026-08-17 fix: bound unresolved plate proxy refinement seeds
2026-08-17 test: pin repaired STEP proxy witnesses
2026-08-17 data: publish certified STEP plate proxies
2026-08-17 docs: clarify unresolved pogo mounting bore
2026-08-17 build: regenerate fail-closed CAD authority artifacts
    [bill_of_materials.csv, hardware_Mill-Max_7983-1-15-20-75-14-11-0_reference.step, so101_matcha_spoon_printed_body.step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]
2026-08-17 feat: reconstruct official pogo mounting authority
2026-08-17 build: regenerate pogo authority artifacts
    [bill_of_materials.csv, electrical_pinout.csv, hardware_Mill-Max_7983-1-15-20-75-14-11-0_reference.step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]
2026-08-17 feat: bind source-coupled capture route
2026-08-17 test: enforce source-coupled capture route
2026-08-17 build: regenerate rolled dock artifacts
    [bill_of_materials.csv, hardware_CS-Q-12-12-04-N.step, hardware_DIN934_M3_lock_stud_nut.step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]
2026-08-19 refactor: remove unused plate proxy authority
2026-08-20 feat: unify interactive scene and video renderer
    [contact-board.stl, dock-support-bracket.stl, generic-tool-plate.stl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]
